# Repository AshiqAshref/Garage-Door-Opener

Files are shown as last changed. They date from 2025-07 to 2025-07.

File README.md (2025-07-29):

# Smart Garage Door Opener

A complete IoT garage door opener system featuring secure Bluetooth Low Energy (BLE) communication, ESP32-C3 microcontroller, custom PCB design, and Android mobile application.

## 🚀 Project Overview

This project implements a modern, secure garage door opener that can be controlled via a smartphone app. The system features:

- **Secure BLE Communication**: Encrypted pairing and authentication
- **ESP32-C3 Based Controller**: Low-power WiFi/BLE microcontroller
- **Custom PCB Design**: Professional circuit board with integrated power management
- **Android Mobile App**: Modern Material Design 3 interface
- **Visual Feedback**: 8-digit LED matrix display for status and pairing codes
- **Physical Controls**: Manual pairing button and factory reset capability

## 📁 Project Structure

```
Garage Door Opener Root/
├── Garage Door Opener Circuit/        # KiCad PCB design files
│   ├── GarageOpener.kicad_sch         # Main schematic
│   ├── GarageOpener.kicad_pcb         # PCB layout
│   ├── production files/              # Gerber files for manufacturing
│   └── parts.txt                      # Bill of materials
├── Garage Door Opener Code/
│   ├── ESP32/                         # Firmware for ESP32-C3
│   │   └── Garage Door Opener/
│   │       ├── src/main.cpp           # Main firmware code
│   │       └── platformio.ini        # PlatformIO configuration
│   └── Android/                       # Android mobile application
│       └── GarageOpenerUI/
│           └── app/src/main/          # Android app source code
├── LICENSE                            # Project license
└── README.md                          # This file
```

## 🔧 Hardware Components

### Main Components
- **ESP32-C3-MINI-1U-N4**: Main microcontroller with WiFi/BLE
- **5V Relay Module**: Controls garage door motor
- **MAX7219 LED Matrix**: 8-digit display for status and pairing codes
- **Buck Converter**: Efficient 5V power supply from mains voltage
- **3.3V Regulator**: Powers ESP32 and logic circuits

### Key Features
- **Input Voltage**: 3.8V - 32V DC input range
- **Power Consumption**: Low-power design with sleep modes
- **Protection**: ESD protection, overcurrent protection
- **Connectivity**: Micro USB for user cusom programming and debugging
- **User Interface**: Physical pairing button, LED status indicators

### PCB Specifications
- **Board Size**: Compact form factor for enclosure mounting
- **Layers**: Multi-layer design for proper power distribution
- **Components**: Surface mount components for reliability
- **Connectors**: Screw terminals for garage door connections

## 💻 Software Features

### ESP32 Firmware
- **Secure BLE Server**: Implements encrypted communication
- **Pairing Management**: Secure device pairing with passkey display
- **Display Controller**: Real-time status updates on LED matrix
- **Memory Management**: Persistent storage of paired devices
- **Factory Reset**: Complete system reset capability

### Android Application
- **Modern UI**: Material Design 3 with Jetpack Compose
- **Device Discovery**: Automatic BLE device scanning
- **Secure Pairing**: Handles BLE security and authentication
- **Device Management**: Save and manage multiple garage door openers
- **Real-time Status**: Live connection status and feedback

## 🔐 Security Features

- **Encrypted BLE Communication**: All data transmitted over encrypted channels
- **Device Authentication**: Secure pairing with passkey verification
- **Bonded Devices**: Only previously paired devices can connect
- **Timeout Protection**: Pairing mode automatically times out
- **Factory Reset**: Complete security reset capability

## 🛠️ Installation & Setup

### Hardware Assembly

1. **PCB Assembly**: Solder all components according to the schematic
2. **Power Connection**: Connect 5-32V DC power supply to input terminals
3. **Relay Wiring**: Connect relay outputs to garage door motor controls
4. **Display Connection**: Wire MAX7219 LED matrix to designated pins
5. **Enclosure**: Mount PCB in weatherproof enclosure

### Firmware Installation

1. **Install PlatformIO**: Set up PlatformIO IDE or VS Code extension
2. **Clone Repository**: Download project files
3. **Configure Platform**: Verify ESP32-C3 platform configuration
4. **Build & Upload**: Compile and flash firmware to ESP32

```bash
cd "Garage Door Opener Code/ESP32/Garage Door Opener"
pio run --target upload
```

### Android App Installation
1. **Easy Install** : Pre built app can be found in ```Garage Door Opener Code/Android/GarageOpenerUI/app/release/app-release.apk``` 

### Android App build
1. **Android Studio**: Open project in Android Studio
2. **Dependencies**: Sync Gradle dependencies
3. **Build Configuration**: Configure signing and build settings
4. **Install**: Build and install APK on Android device

```bash
cd "Garage Door Opener Code/Android/GarageOpenerUI"
./gradlew assembleRelease
```

## 📱 Usage Instructions

### Initial Setup

1. **Power On**: Connect power to the garage door opener
2. **Pairing Mode**: Press and hold the pairing button for 5 seconds
3. **Mobile App**: Open the Android app and scan for devices
4. **Select Device**: Choose "Garage" from the discovered devices list
5. **Enter Passkey**: Input the 6-digit code displayed on the LED matrix
6. **Complete Pairing**: Confirm pairing on both devices

### Daily Operation

1. **Open App**: Launch the Garage Opener app on your phone
2. **Connect**: App automatically connects to paired device
3. **Control**: Tap the garage door button to operate
4. **Status**: Monitor connection status via app interface

### Advanced Features

- **Multiple Devices**: Pair multiple garage door openers
- **Device Management**: Remove or re-pair devices as needed
- **Factory Reset**: Hold pairing button for 10 seconds to reset

## 🔌 Pin Configuration

### ESP32-C3 Pin Assignments
```cpp
#define RELAY_PIN 12        // Garage door relay control
#define BUTTON_PIN 13       // Pairing/reset button
#define DIN_PIN 21          // MAX7219 data input
#define CS_PIN 19           // MAX7219 chip select
#define CLK_PIN 18          // MAX7219 clock
```

### Power Requirements
- **Input Voltage**: 5V - 32V DC
- **ESP32 Current**: ~80mA active, ~10µA deep sleep
- **Relay Current**: ~70mA when activated
- **Display Current**: ~20mA typical

## 🐛 Troubleshooting

### Common Issues

**Cannot pair device:**
- Ensure Bluetooth is enabled on phone
- Verify device is in pairing mode (LED shows passkey)
- Check app permissions for Bluetooth access

**Relay not activating:**
- Verify power supply voltage (5V minimum)
- Check relay connections and wiring
- Test relay manually with multimeter

**Display not working:**
- Confirm MAX7219 connections and power
- Verify pin assignments in firmware
- Check display module with simple test code

**Connection drops frequently:**
- Reduce distance between phone and device
- Check for interference from other 2.4GHz devices
- Verify phone's Bluetooth Low Energy support

## 🔧 Development

### Building from Source

**Requirements:**
- PlatformIO Core 6.0+
- Android Studio Arctic Fox+
- ESP32 Arduino Core 2.0+
- Android API Level 30+

**ESP32 Development:**
```bash
# Install dependencies
pio pkg install

# Build firmware
pio run

# Upload to device
pio run --target upload

# Monitor serial output
pio device monitor
```

**Android Development:**
```bash
# Build debug APK
./gradlew assembleDebug

# Run tests
./gradlew test

# Generate release APK
./gradlew assembleRelease
```

### Code Structure

**ESP32 Firmware:**
- `main.cpp`: Main application logic and BLE server
- `LedController.hpp`: MAX7219 display management
- `platformio.ini`: Build configuration and dependencies

**Android Application:**
- `MainActivity.kt`: Main UI and app lifecycle
- `BleService.kt`: Bluetooth Low Energy communication
- `build.gradle.kts`: Build configuration and dependencies

## 📋 Bill of Materials (BOM)

### Critical Components
| Component | Part Number | Quantity | Description |
|---|---|---|---|
| ESP32-C3-MINI-1U-N4 | ESP32-C3-MINI-1U-N4 | 1 | Main microcontroller |
| Relay | SRD-05VDC-SL-C | 1 | 5V SPDT relay |
| Buck Converter IC | TBD | 1 | 5V switching regulator |
| LED Matrix | MAX7219 8-digit | 1 | Status display |
| Capacitors | Various | Multiple | Power filtering |
| Resistors | Various | Multiple | Pull-ups and current limiting |

*See `parts.txt` for complete component specifications*

## 🤝 Contributing

Contributions are welcome! Please follow these guidelines:

1. **Fork the Repository**: Create your own fork
2. **Create Feature Branch**: `git checkout -b feature/new-feature`
3. **Commit Changes**: Use descriptive commit messages
4. **Push Branch**: `git push origin feature/new-feature`
5. **Create Pull Request**: Submit PR with detailed description

### Development Standards
- Follow existing code style and formatting
- Add comments for complex logic
- Test thoroughly before submitting
- Update documentation as needed

## 📄 License

This project is licensed under the MIT License - see the [LICENSE](LICENSE) file for details.

## ⚠️ Safety Warning

**ELECTRICAL SAFETY**: This device interfaces with garage door motors that operate at dangerous voltages. Installation should only be performed by qualified electricians. Always disconnect power before making connections.

**SECURITY**: While this system implements encryption, no system is 100% secure. Use appropriate physical security measures for your garage.

## 📞 Support

For questions, issues, or contributions:
- **Issues**: Use GitHub Issues for bug reports
- **Discussions**: GitHub Discussions for general questions
- **Email**: Contact project maintainer for urgent issues

## 🔄 Version History

- **v1.0**: Initial release with basic BLE functionality
- **Future**: Planned features include WiFi connectivity, web interface, and voice control integration

---

**Built with ❤️ for the maker community**

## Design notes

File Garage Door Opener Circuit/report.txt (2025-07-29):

Plotted to 'E:\Project\Kicad\firstTry\firstTry.pdf'.

Info: Done.
Plotted to 'E:\Project\Kicad\firstTry\firstTry.pdf'.

Info: Done.
Info: Done.
Info: Done.

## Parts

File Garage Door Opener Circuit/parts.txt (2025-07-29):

tantalum cap C6- TAJA226K010TNJ or TAJA226K010RNJ esr betwen 0.2 Ohm to 10 Ohm
C1 - CAPACITOR_SMD CER 1uf 603 : CL10B105KO8NNNC, CL10B105KO8NNNC
C4 - CL31B106KAHNNNE 10uf +/-10% 25V 1206

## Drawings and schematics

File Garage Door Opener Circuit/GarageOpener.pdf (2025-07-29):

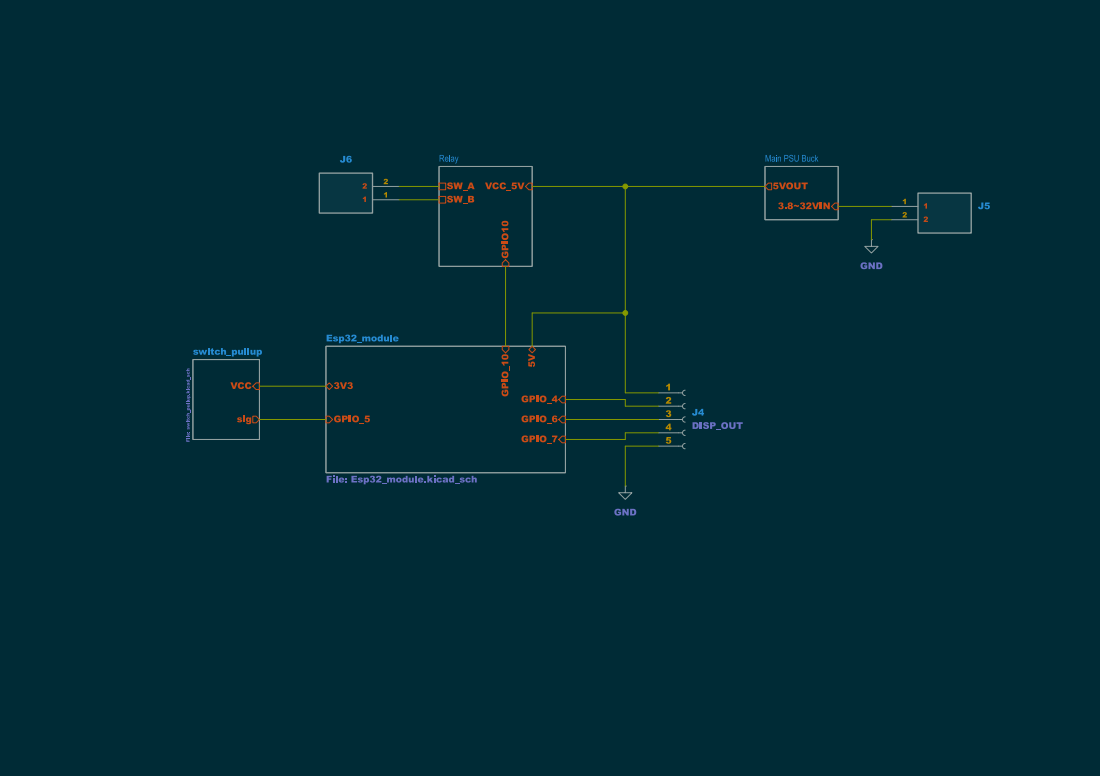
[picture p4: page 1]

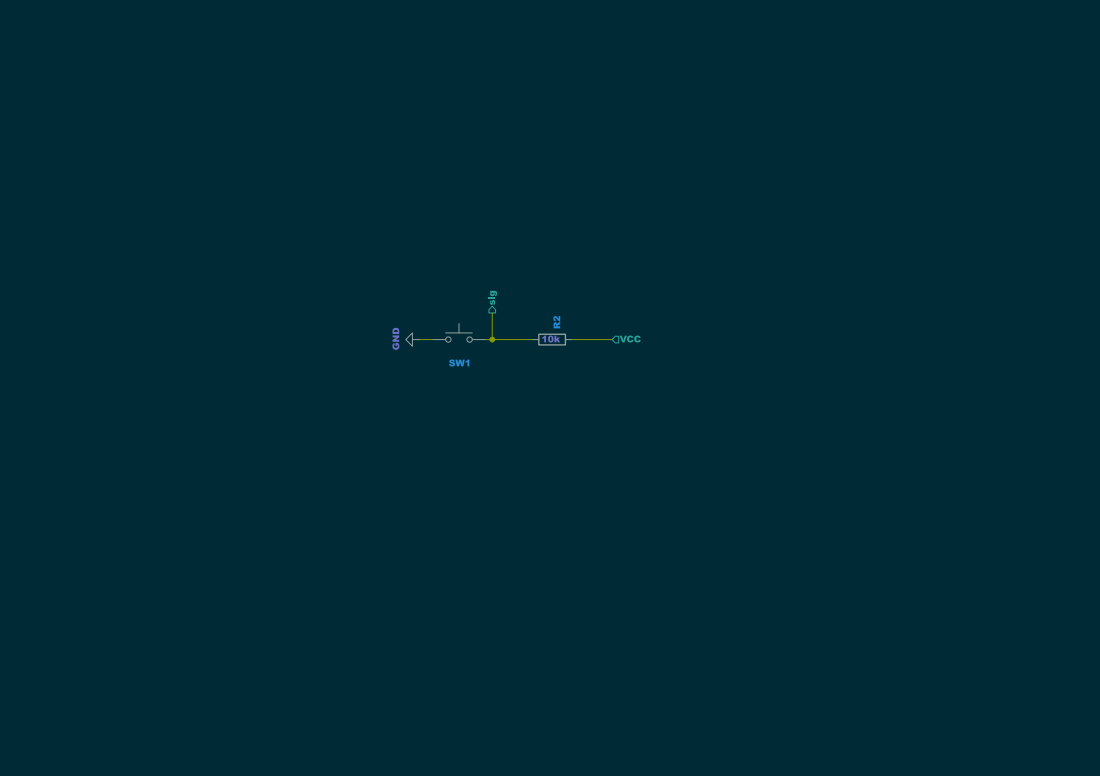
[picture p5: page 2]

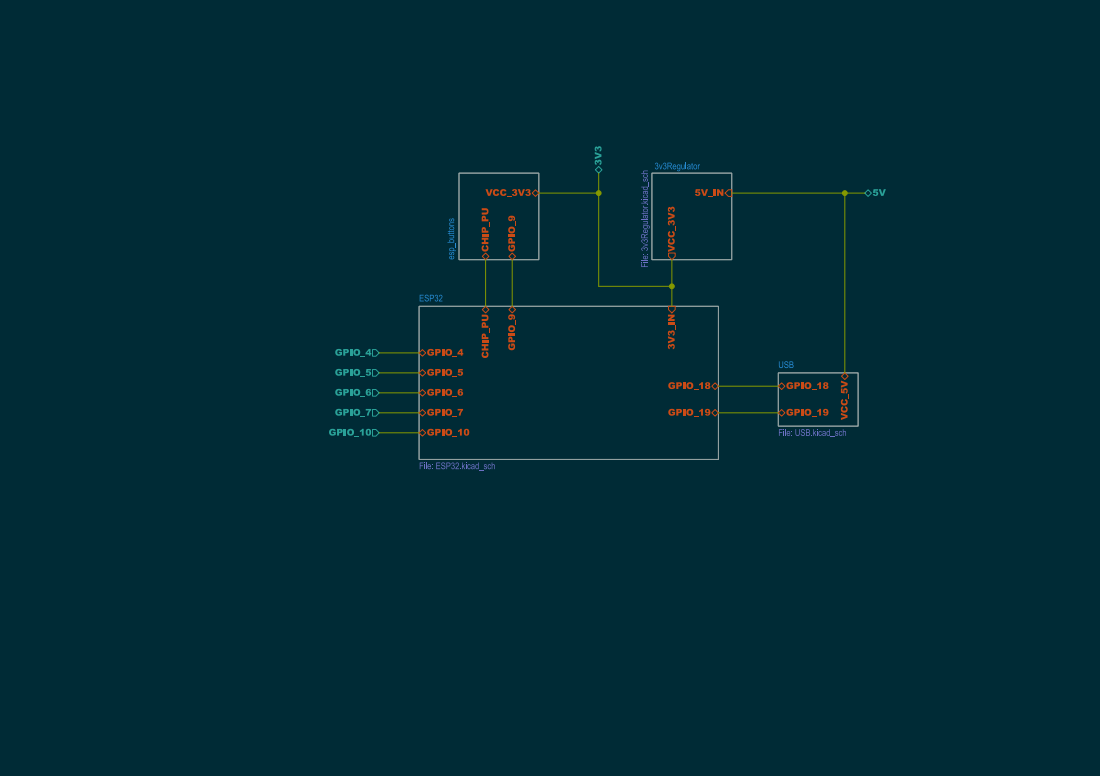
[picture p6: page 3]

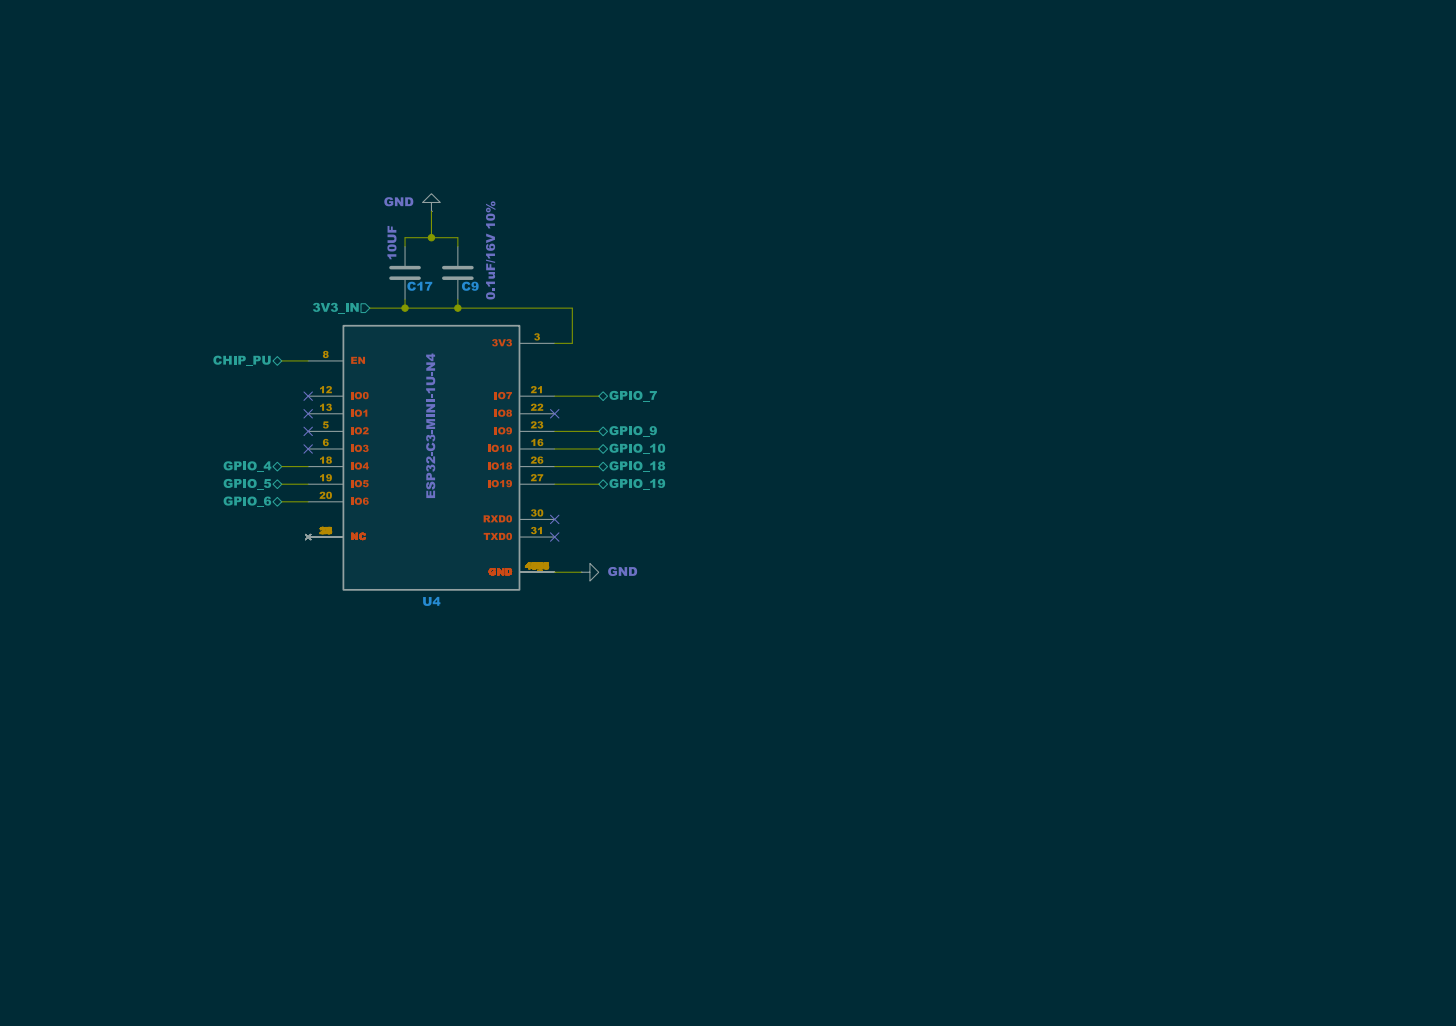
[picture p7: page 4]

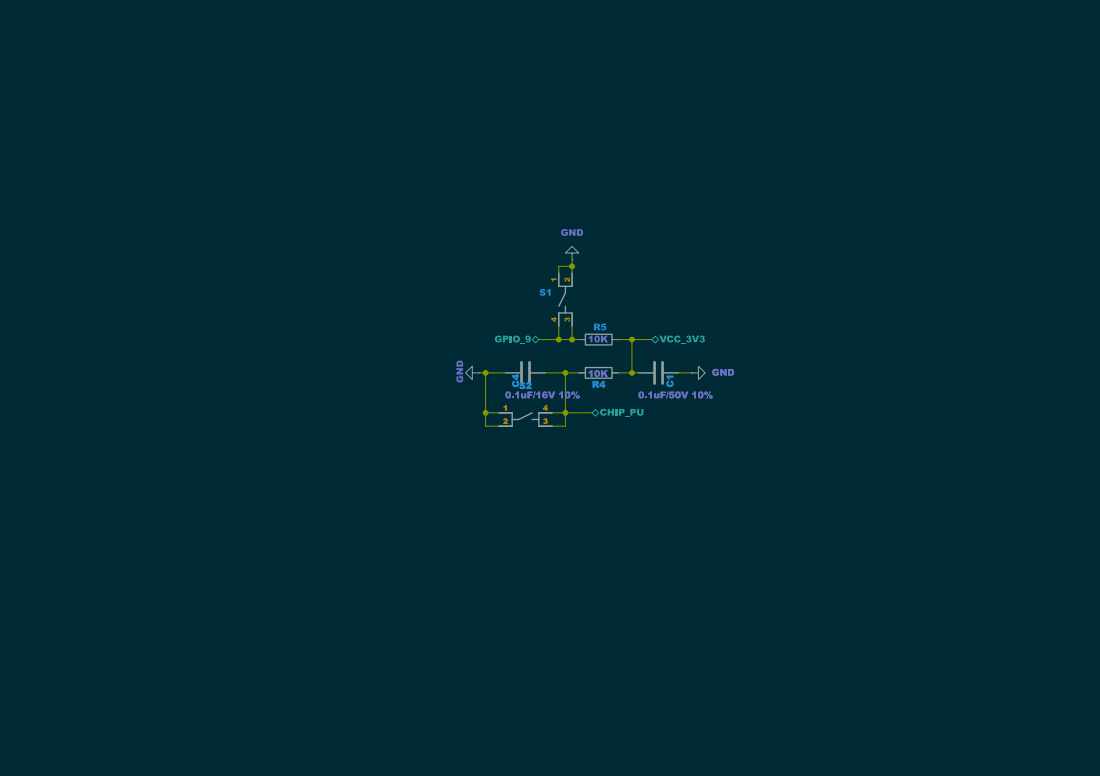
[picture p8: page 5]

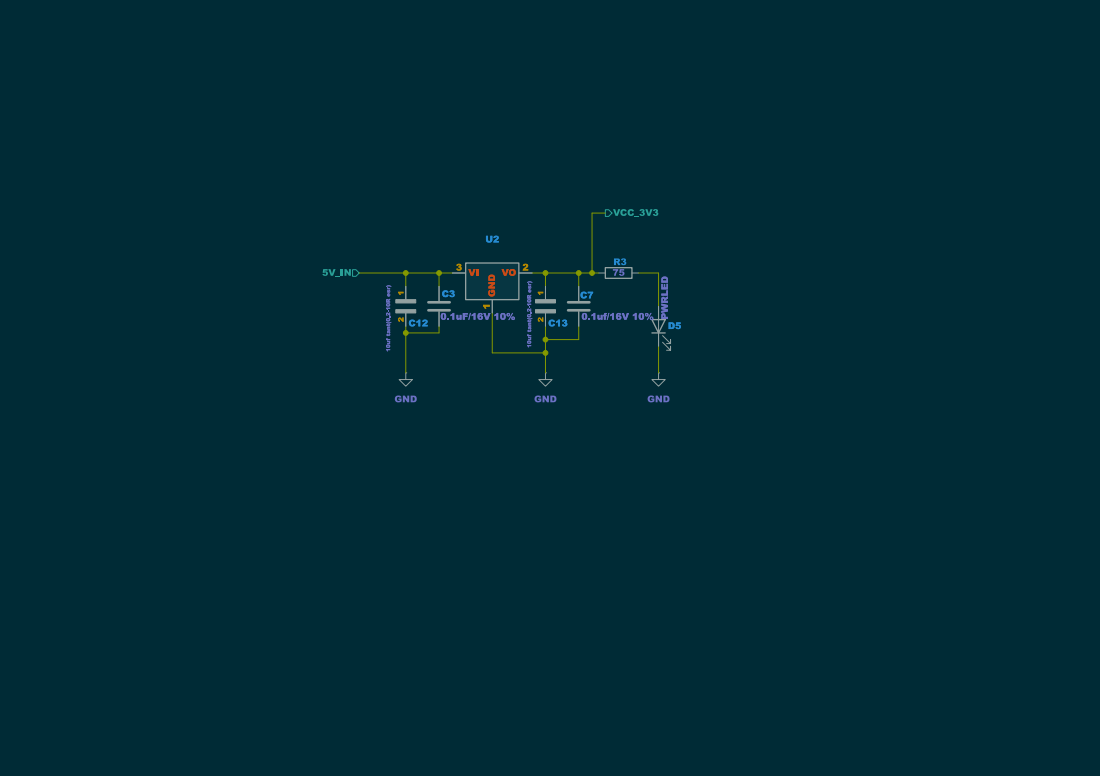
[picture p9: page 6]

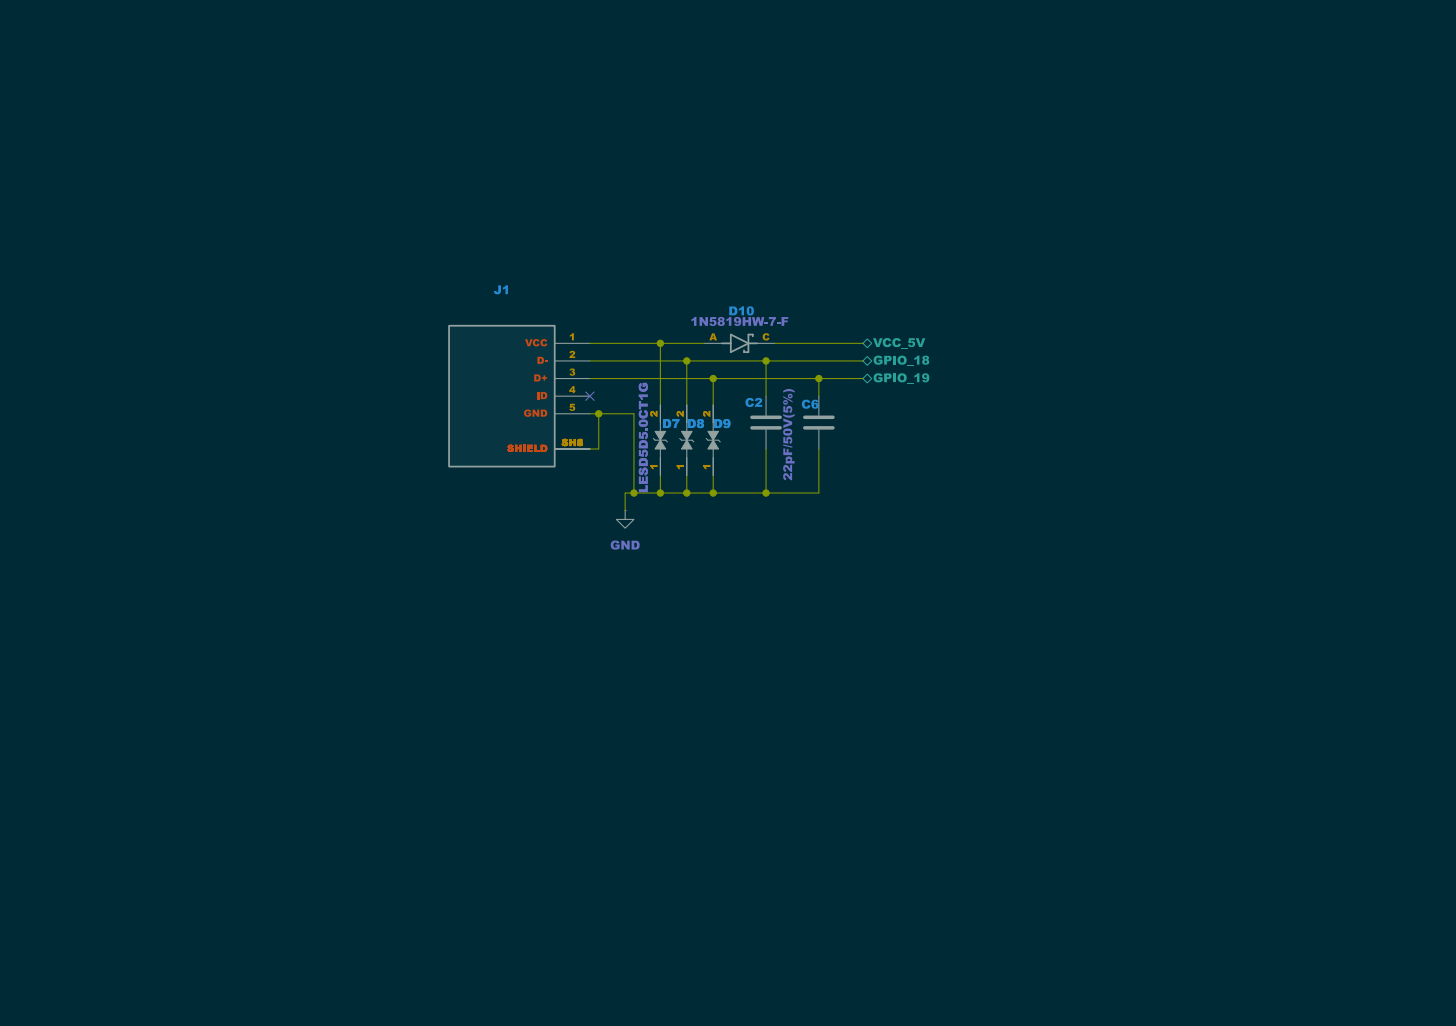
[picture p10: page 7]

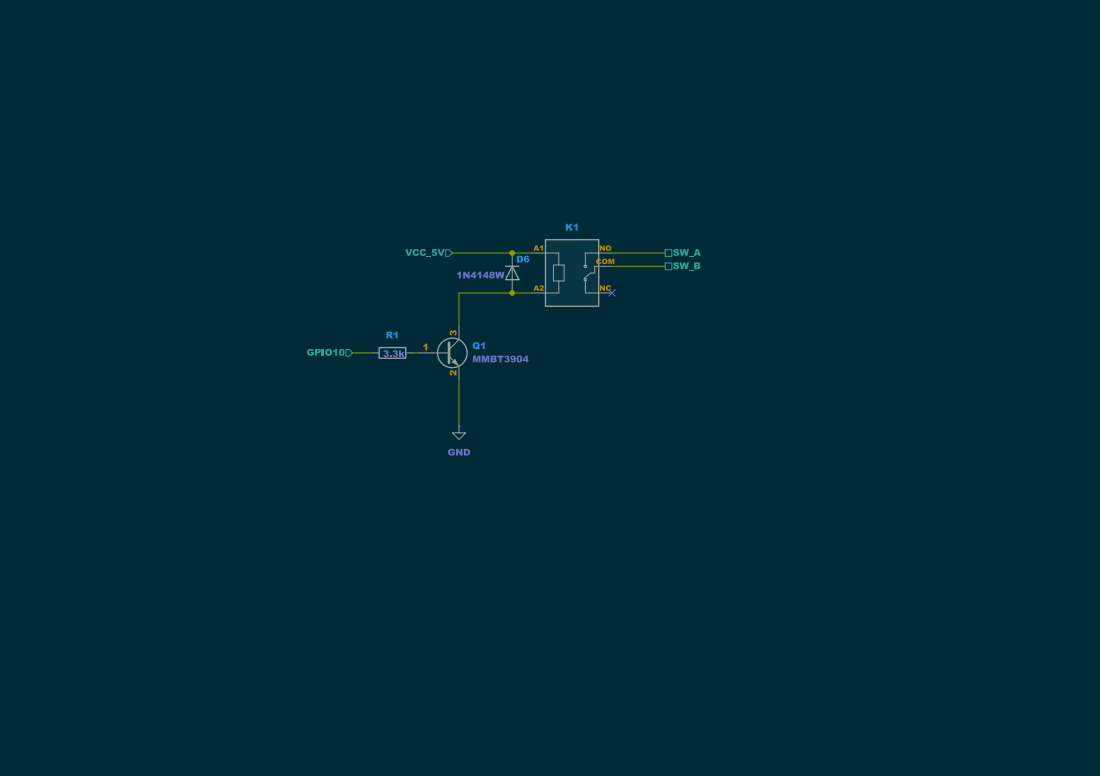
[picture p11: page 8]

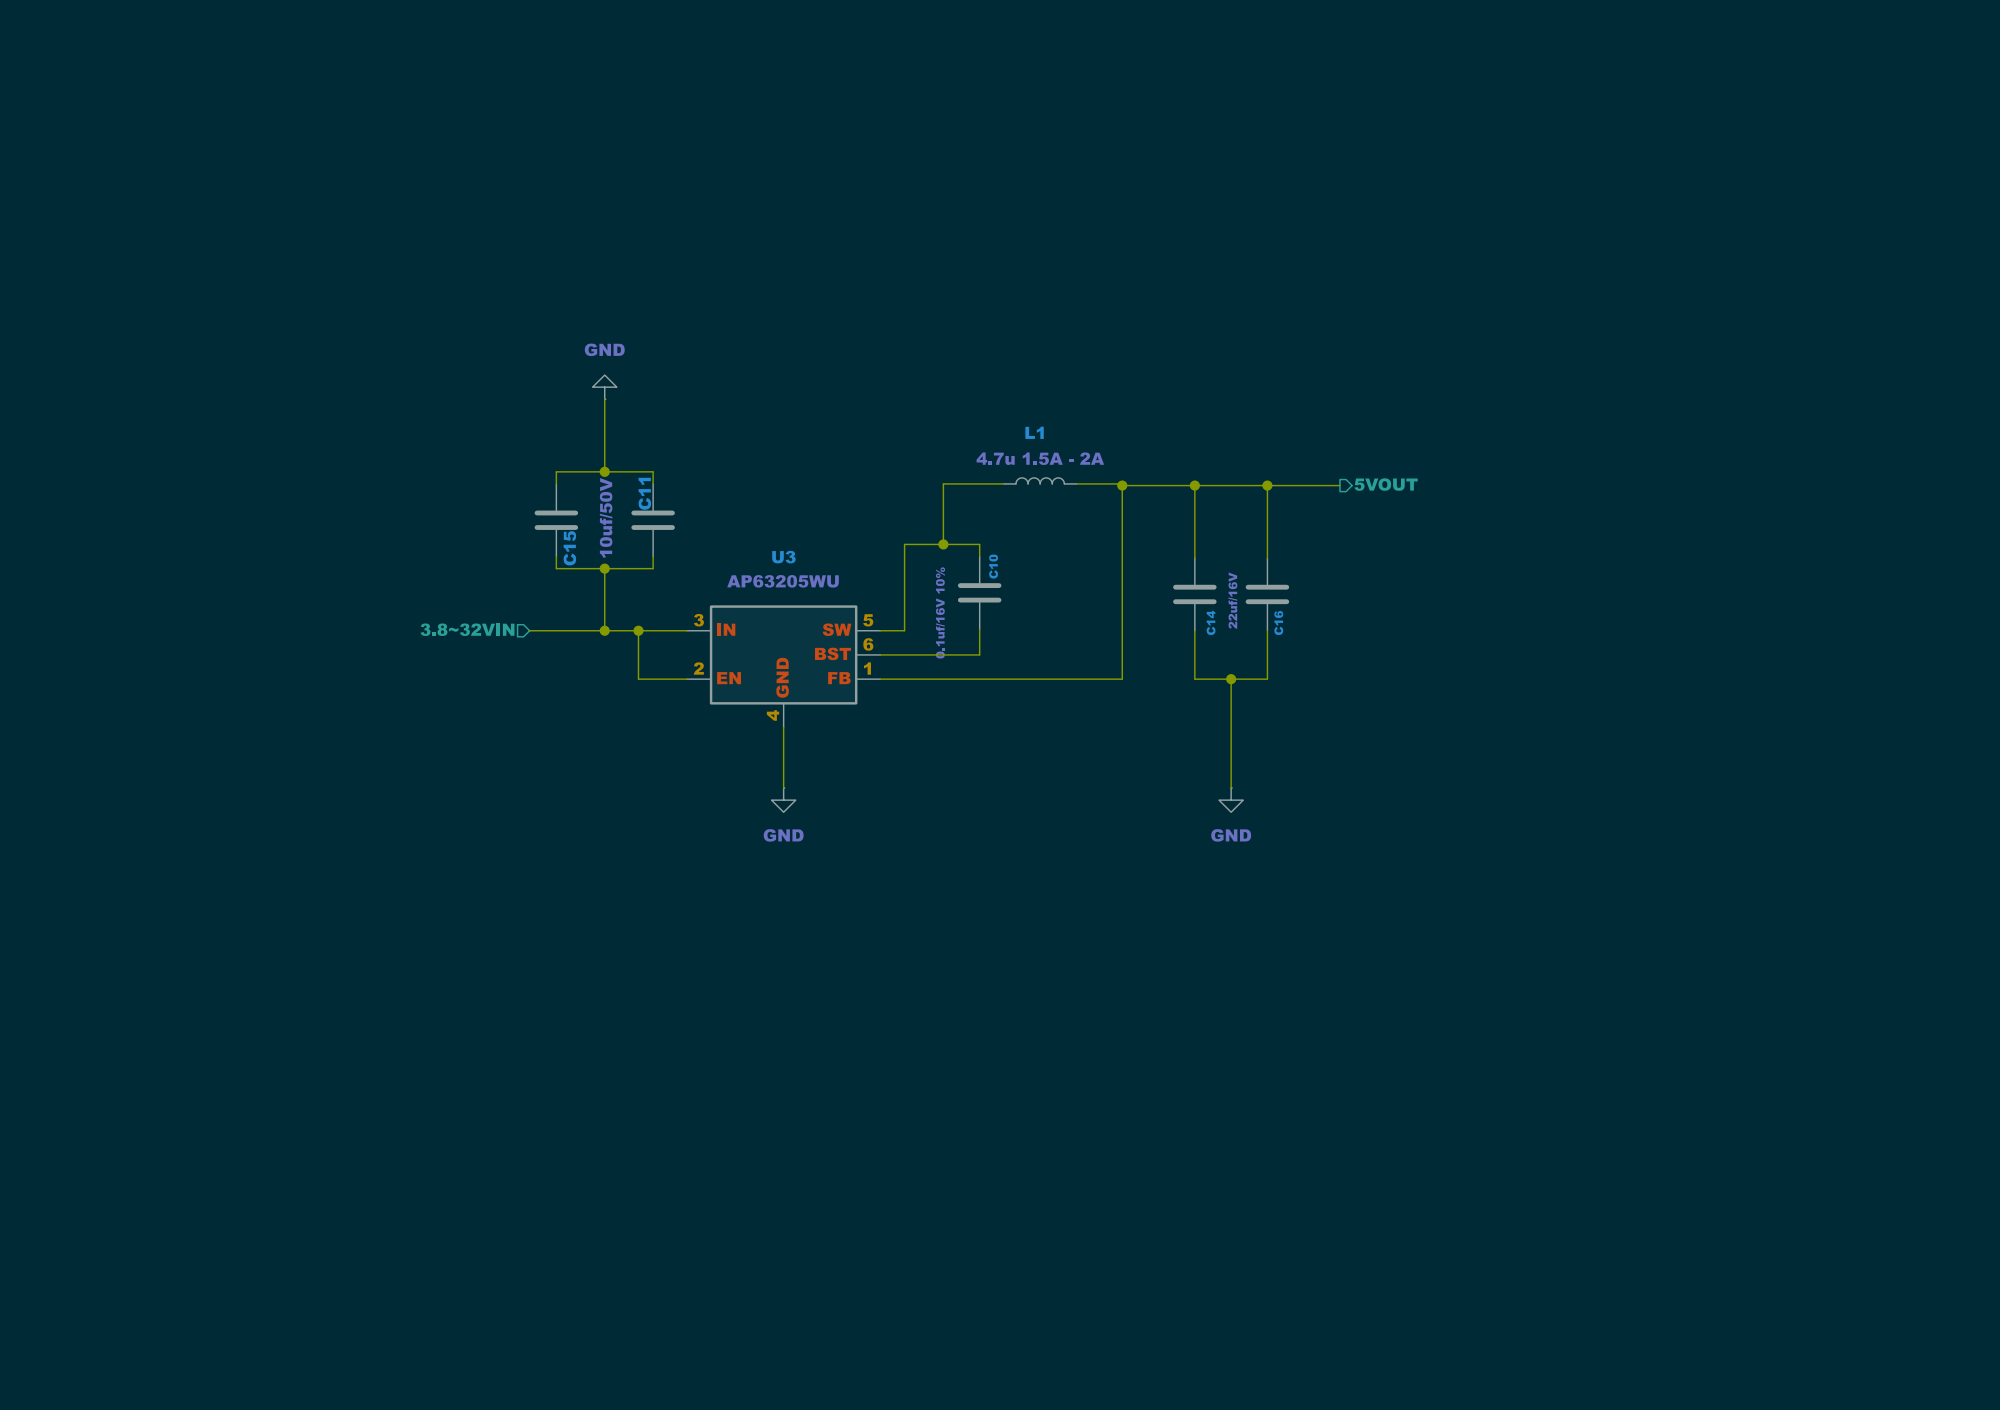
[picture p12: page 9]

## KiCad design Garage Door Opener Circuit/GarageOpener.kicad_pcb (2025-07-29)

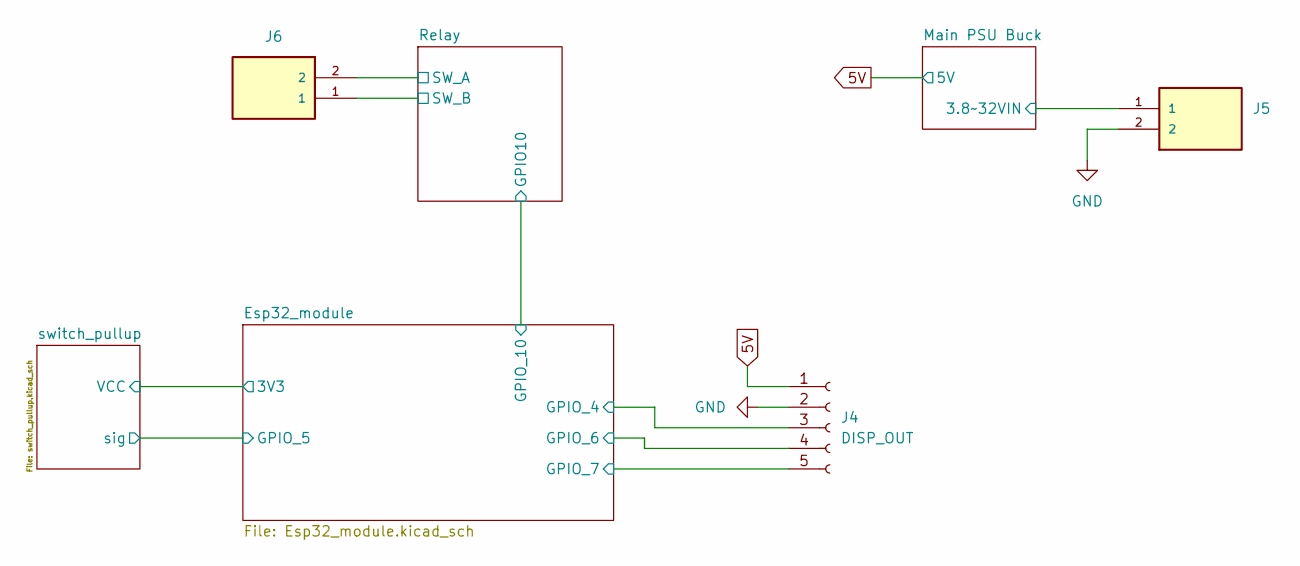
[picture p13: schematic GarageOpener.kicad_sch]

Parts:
J4: DISP_OUT; PinHeader_1x05_P2.54mm_Vertical
J5, J6: TB002-500-02BE; CUI_TB002-500-02BE

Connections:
5V: J4.1; also elsewhere on the board
/Esp32_module/GPIO_4: J4.3; also elsewhere on the board
/Esp32_module/GPIO_6: J4.4; also elsewhere on the board
/Esp32_module/GPIO_7: J4.5; also elsewhere on the board
/Main PSU Buck/3.8~32VIN: J5.1; also elsewhere on the board
/Relay/SW_A: J6.2; also elsewhere on the board
/Relay/SW_B: J6.1; also elsewhere on the board
GND: J4.2, J5.2; also elsewhere on the board

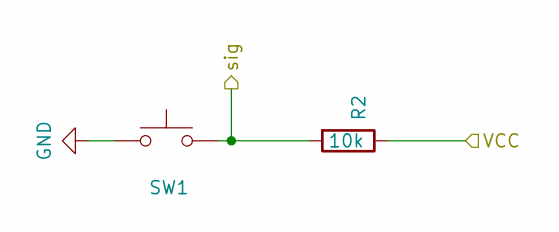
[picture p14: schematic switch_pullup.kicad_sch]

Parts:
R2: 10k; R_0402_1005Metric
SW1: SW_Push; SW_SPST_PTS645Sx43SMTR92

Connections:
3V3: R2.1; also elsewhere on the board
/Esp32_module/GPIO_5: R2.2, SW1.2; also elsewhere on the board
GND: SW1.1; also elsewhere on the board

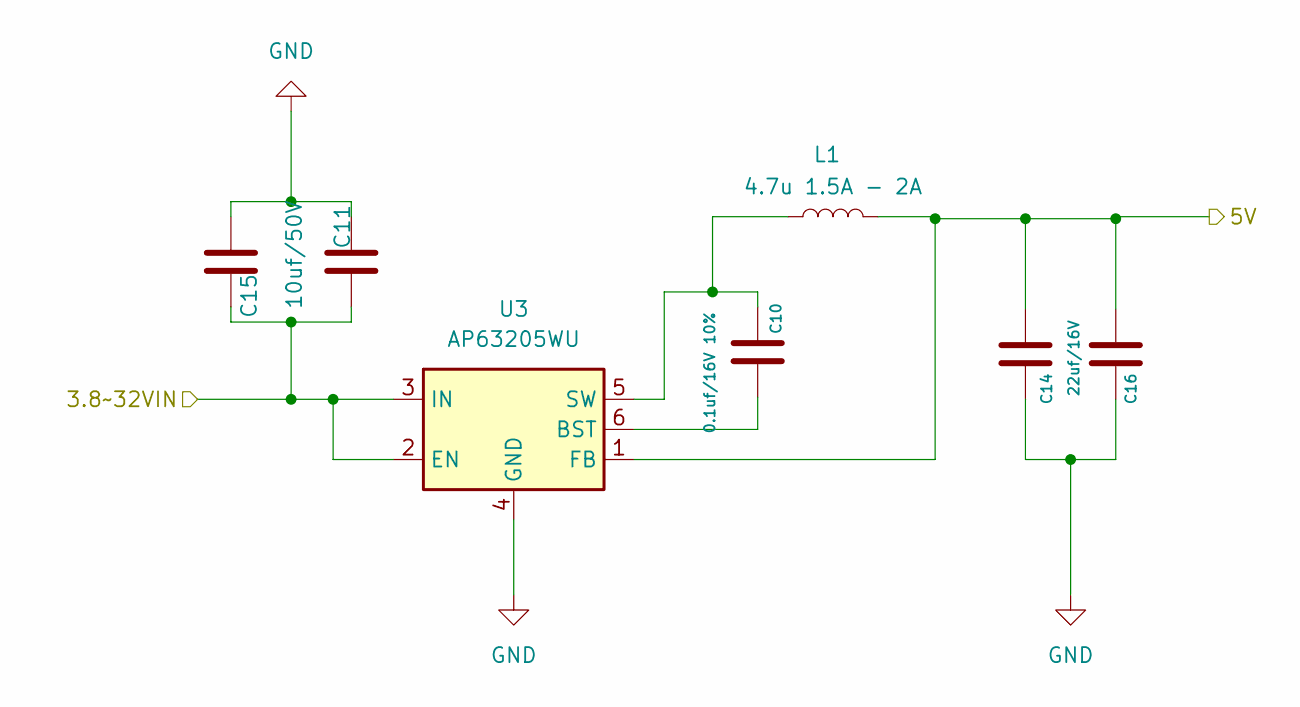
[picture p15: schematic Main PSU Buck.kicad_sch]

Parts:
C10: 0.1uf/16V 10%; C_0201_0603Metric
C11, C15: 10uf/50V; CAPC3225X270N
C14, C16: 22uf/16V; CAPC1608X100N
L1: 4.7u 1.5A - 2A; IND_NRS5030T100MMGJ_TAY
U3: AP63205WU; TSOT-23-6

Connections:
5V: C14.1, C16.1, L1.2, U3.1 (FB); also elsewhere on the board
/Main PSU Buck/3.8~32VIN: C11.2, C15.2, U3.2 (EN), U3.3 (IN); also elsewhere on the board
GND: C11.1, C14.2, C15.1, C16.2, U3.4 (GND); also elsewhere on the board
unnamed: C10.2, U3.6 (BST)
unnamed: C10.1, L1.1, U3.5 (SW)

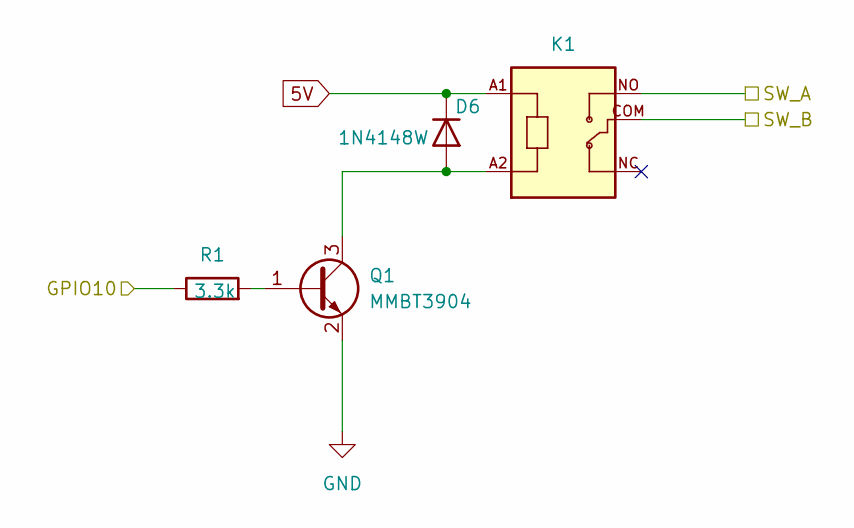
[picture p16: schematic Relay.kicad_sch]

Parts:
D6: 1N4148W; D_SOD-123
K1: SRD-05VDC-SL-C; RELAY_SRD-05VDC-SL-C
Q1: MMBT3904; SOT-23
R1: 3.3k; R_0603_1608Metric

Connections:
5V: D6.1 (K), K1.A1; also elsewhere on the board
/Esp32_module/GPIO_10: R1.1; also elsewhere on the board
/Relay/SW_A: K1.NO; also elsewhere on the board
/Relay/SW_B: K1.COM; also elsewhere on the board
GND: Q1.2 (E); also elsewhere on the board
unnamed: D6.2 (A), K1.A2, Q1.3 (C)
unnamed: Q1.1 (B), R1.2

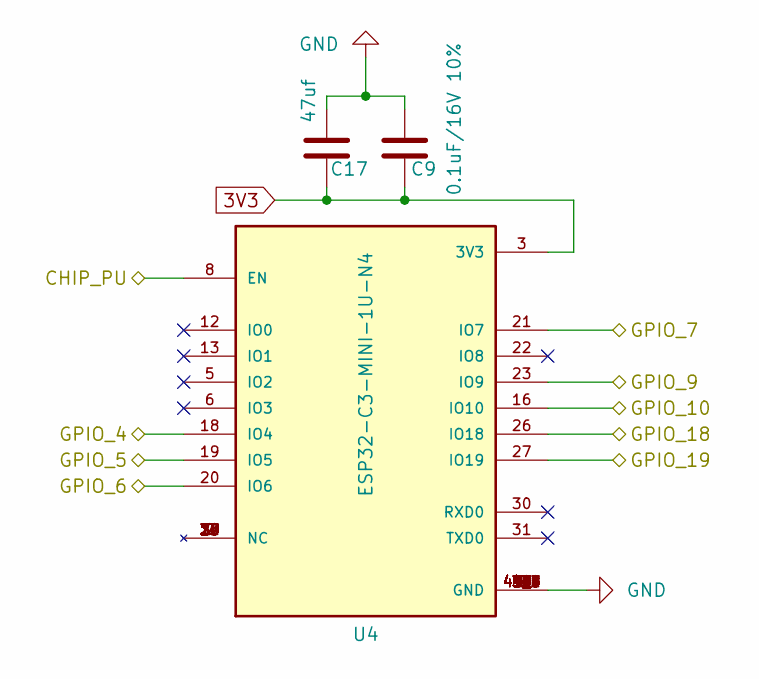
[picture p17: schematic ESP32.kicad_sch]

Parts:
C9: 0.1uF/16V 10%; VARC3216X85N
C17: 47uf; C_1206_3216Metric
U4: ESP32-C3-MINI-1U-N4; XCVR_ESP32-C3-MINI-1U-N4; PARTREV v1.0

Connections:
3V3: C9.1, C17.1, U4.3 (3V3); also elsewhere on the board
/Esp32_module/ESP32/CHIP_PU: U4.8 (EN); also elsewhere on the board
/Esp32_module/ESP32/GPIO_9: U4.23 (IO9); also elsewhere on the board
/Esp32_module/ESP32/GPIO_18: U4.26 (IO18); also elsewhere on the board
/Esp32_module/ESP32/GPIO_19: U4.27 (IO19); also elsewhere on the board
/Esp32_module/GPIO_4: U4.18 (IO4); also elsewhere on the board
/Esp32_module/GPIO_5: U4.19 (IO5); also elsewhere on the board
/Esp32_module/GPIO_6: U4.20 (IO6); also elsewhere on the board
/Esp32_module/GPIO_7: U4.21 (IO7); also elsewhere on the board
/Esp32_module/GPIO_10: U4.16 (IO10); also elsewhere on the board
GND: C9.2, C17.2, U4.1 (GND), U4.2 (GND), U4.11 (GND), U4.14 (GND), U4.36 (GND), U4.37 (GND), U4.38 (GND), U4.39 (GND), U4.40 (GND), U4.41 (GND), U4.42 (GND), U4.43 (GND), U4.44 (GND), U4.45 (GND), U4.46 (GND), U4.47 (GND), U4.48 (GND), U4.49_1 (GND), U4.49_2 (GND), U4.49_3 (GND), U4.49_4 (GND), U4.49_5 (GND), U4.49_6 (GND), U4.49_7 (GND), U4.49_8 (GND), U4.49_9 (GND), U4.50 (GND), U4.51 (GND), U4.52 (GND), U4.53 (GND); also elsewhere on the board

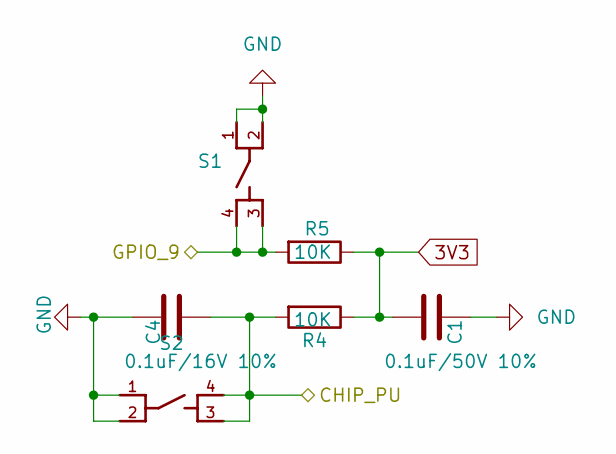
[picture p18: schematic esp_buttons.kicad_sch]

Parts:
C1: 0.1uF/50V 10%; C_0201_0603Metric
C4: 0.1uF/16V 10%; C_0201_0603Metric
R4, R5: 10K; R_0402_1005Metric
S1, S2: PTS526_SMG15_SMTR2_LFS; SW_PTS526_SMG15_SMTR2_LFS

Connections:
3V3: C1.1, R4.1, R5.1; also elsewhere on the board
/Esp32_module/ESP32/CHIP_PU: C4.2, R4.2, S2.3, S2.4; also elsewhere on the board
/Esp32_module/ESP32/GPIO_9: R5.2, S1.3, S1.4; also elsewhere on the board
GND: C1.2, C4.1, S1.1, S1.2, S2.1, S2.2; also elsewhere on the board

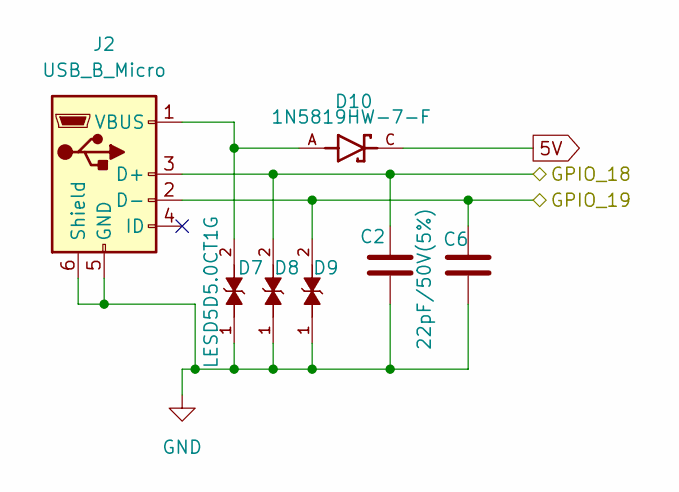
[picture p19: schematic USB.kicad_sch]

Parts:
C2, C6: 22pF/50V(5%); C_0201_0603Metric
D7, D8, D9: LESD5D5.0CT1G; TVS_LESD5D5.0CT1G; PARTREV O
D10: 1N5819HW-7-F; SOD3715X145N; PARTREV 18-2; DigiKey_Part_Number 1N5819HW-FDITR-ND
J2: USB_B_Micro; USB_Micro-B_Amphenol_10118194_Horizontal

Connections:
5V: D10.C; also elsewhere on the board
/Esp32_module/ESP32/GPIO_18: C2.1, D8.2, J2.3 (D+); also elsewhere on the board
/Esp32_module/ESP32/GPIO_19: C6.1, D9.2, J2.2 (D-); also elsewhere on the board
GND: C2.2, C6.2, D7.1, D8.1, D9.1, J2.5 (GND), J2.6 (Shield); also elsewhere on the board
unnamed: D7.2, D10.A, J2.1 (VBUS)

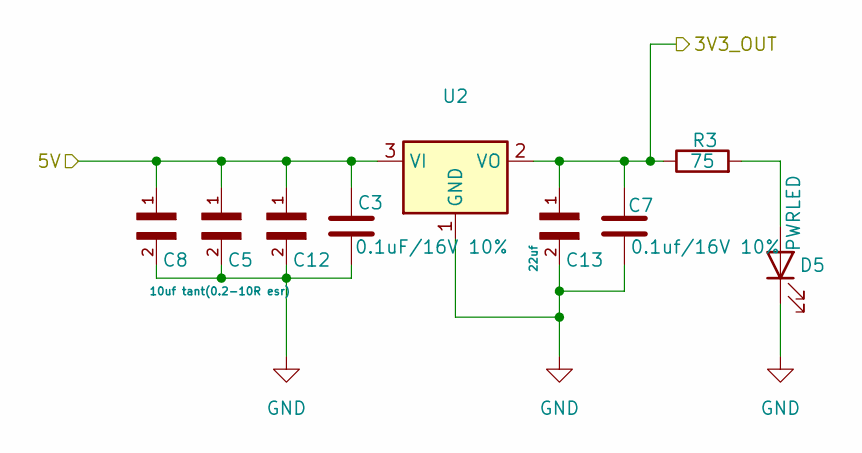
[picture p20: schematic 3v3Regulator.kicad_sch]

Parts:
C3: 0.1uF/16V 10%; VARC3216X85N
C5, C8, C12: 10uf tant(0.2-10R esr); C_1206_3216Metric
C7: 0.1uf/16V 10%; VARC3216X85N
C13: 22uf; C_1206_3216Metric
D5: PWRLED; 0603
R3: 75; R_0402_1005Metric
U2: AMS1117-3.3; SOT-223-3_TabPin2

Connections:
3V3: C7.1, C13.1, R3.1, U2.2 (VO); also elsewhere on the board
5V: C3.1, C5.1, C8.1, C12.1, U2.3 (VI); also elsewhere on the board
GND: C3.2, C5.2, C7.2, C8.2, C12.2, C13.2, D5.1 (K), U2.1 (GND); also elsewhere on the board
unnamed: D5.2 (A), R3.2

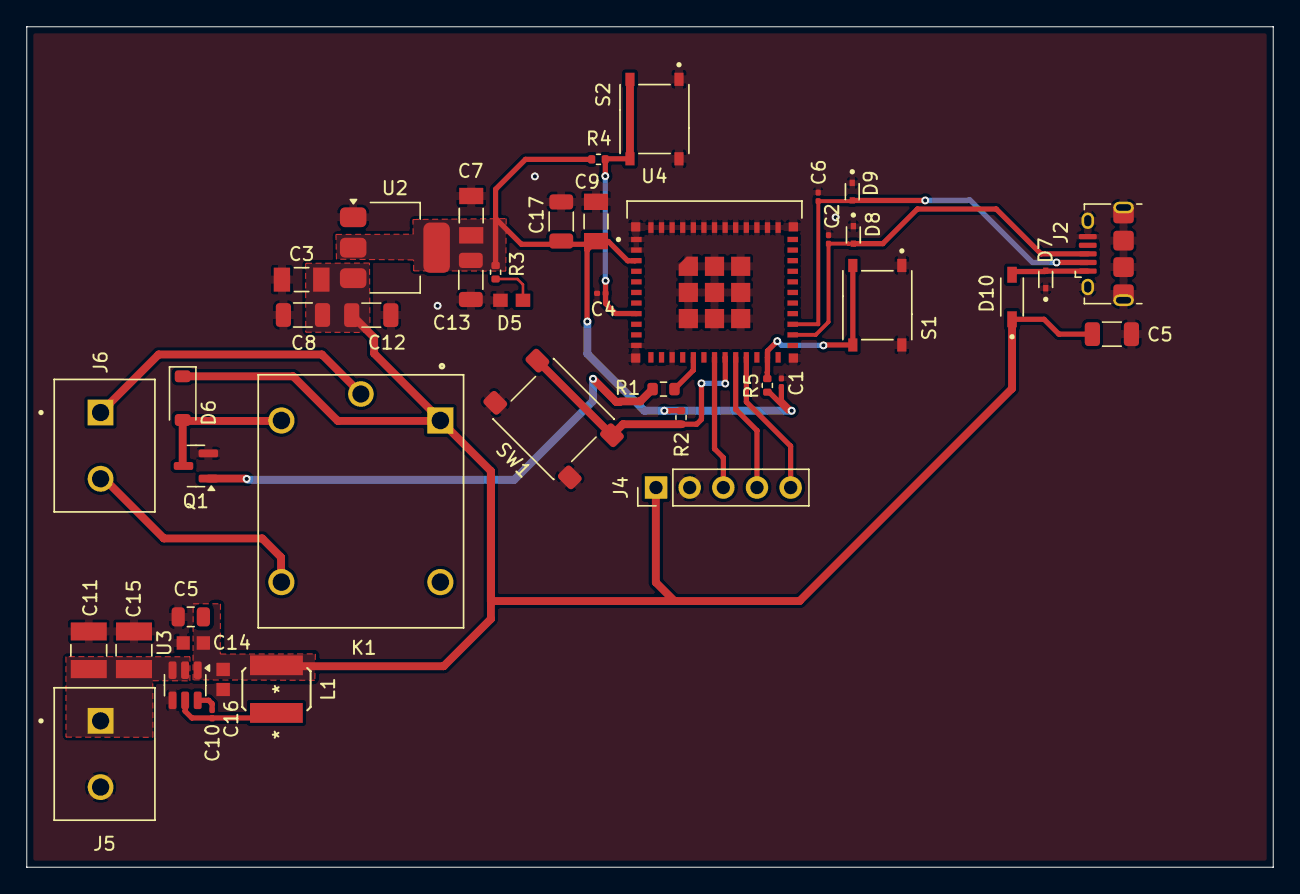
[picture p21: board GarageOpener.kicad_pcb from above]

Board: 2 copper layers, 94.1 x 63.5 mm, 42 parts (0 on the bottom side), 21 nets.

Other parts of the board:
C5#2: 0.1uF/16V 10%; C_0805_2012Metric

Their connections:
GND: C5#2.2; also elsewhere on the board

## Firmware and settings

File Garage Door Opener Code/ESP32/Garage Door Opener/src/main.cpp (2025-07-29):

#include <Arduino.h>
#include <BLEDevice.h>
#include <BLEUtils.h>
#include <BLEServer.h>
#include <BLE2902.h>

#include "LedController.hpp"
#include <Preferences.h>

#include "esp_gap_ble_api.h" // Required for esp_ble_get_bond_device_num() and esp_ble_get_bond_device_list()
#include "esp_bt.h"         // Required for esp_ble_bond_dev_t struct definition

// GPIO pin connected to the relay that controls the garage door
#define RELAY_PIN 12
// #define BUTTON_PIN 27
#define BUTTON_PIN 13

// GPIO pins for the MAX7219 LED Matrix 8 digit display
constexpr int DIN_PIN = 21;
constexpr int CS_PIN  = 19;
constexpr int CLK_PIN = 18;

// UUID generator : https://www.uuidgenerator.net/
#define SERVICE_UUID        "9ba08ea3-3fa9-4622-bae5-bdd3f0c7fedf" // Example Service UUID
#define CHARACTERISTIC_UUID "427c5c12-0f90-46be-ba43-7e4a207be489" // Example Characteristic UUID

// Global pointers for BLE objects
BLEServer* pServer = nullptr;
BLECharacteristic* pCharacteristic = nullptr;

// Create an instance of the LedController
LedController lc = LedController();

// Flags to track connection status for re-advertising
bool deviceConnected = false;
bool oldDeviceConnected = false;

uint32_t currentDisplayedPasskey = 0;

//pairing button
constexpr unsigned long PAIRING_PRESS_DURATION_MILLIS = 5000; // 5 seconds
constexpr unsigned long PAIRING_WINDOW_TIMEOUT_MILLIS = 60000; // Advertising active for 60 seconds if no connection
constexpr unsigned long FACTORY_RESET_PRESS_DURATION = 5000; // 5 seconds for factory reset
bool pairingModeActive = false;  // True if the device is currently advertising for new pairings
bool allowNewPairing = false;    // Only true during explicit pairing mode activated by button
unsigned long buttonPressStartTime = 0; // Tracks when the pairing button was first pressed
unsigned long pairingModeStartTime = 0; // Tracks when pairing mode was activated, for timeout

unsigned long lastDisplayUpdate = 0; // Timestamp for the last display update


Preferences preferences;

// Add this function to your code
void clearBondedDevices() {
    Serial.println("Clearing all bonded devices from NVS...");
    preferences.begin("nvs", false); // Open preferences with namespace "nvs" where ESP32 BT/BLE info is stored
    preferences.clear(); // Clear all preferences under this namespace
    preferences.end(); // Close the preferences

    Serial.println("All bonded devices have been removed. Restarting...");
    ESP.restart();
}

// Function to list all currently bonded devices stored in NVS flash
void listBondedDevices() {
    Serial.println("\n--- Listing Bonded Devices ---");

    // Get the number of bonded devices
    int dev_num = esp_ble_get_bond_device_num(); 

    if (dev_num <= 0) {
        Serial.println("No bonded devices found.");
        return;
    }

    // Allocate memory to hold the list of bonded device structures
    // It's crucial to free this memory after use.
    auto *bond_dev_list = static_cast<esp_ble_bond_dev_t *>(heap_caps_malloc(sizeof(esp_ble_bond_dev_t) * dev_num,
                                                                             MALLOC_CAP_INTERNAL | MALLOC_CAP_8BIT));

    if (!bond_dev_list) {
        Serial.println("ERROR: Failed to allocate memory for bond device list.");
        return;
    }

    // Retrieve the list of bonded devices
    // The first argument `&dev_num` will be updated with the actual number of devices retrieved.
    esp_ble_get_bond_device_list(&dev_num, bond_dev_list);

    Serial.printf("%d bonded device(s) found:\n", dev_num);
    for (int i = 0; i < dev_num; i++) {
        // Print the MAC address of each bonded device
        Serial.printf("  Device %d: %02X:%02X:%02X:%02X:%02X:%02X\n", i + 1,
                        bond_dev_list[i].bd_addr[0], bond_dev_list[i].bd_addr[1],
                        bond_dev_list[i].bd_addr[2], bond_dev_list[i].bd_addr[3],
                        bond_dev_list[i].bd_addr[4], bond_dev_list[i].bd_addr[5]);
        // You could also inspect bond_dev_list[i].addr_type if you need to differentiate
        // between public and random addresses, though for most uses, the address itself is enough.
    }

    // Free the allocated memory to prevent memory leaks
    heap_caps_free(bond_dev_list); 
    Serial.println("--- End of Bonded Devices List ---");
}


void displayString(const String& str, uint8_t startSegment, const String& prefix = "") {
    if (pairingModeActive && currentDisplayedPasskey > 0) {
        return; // If pairing mode is active, do not update the display with passkeys
    }
    lastDisplayUpdate = millis(); // Update the timestamp for the last display update
    lc.clearMatrix();  
    const uint32_t len = str.length();
    
    uint8_t segPos;
    if(startSegment > 7) { len>7 ? segPos = 7: segPos=len; } 
    else { segPos = 7 - startSegment; }
    
    if(prefix.length() > 0) {
        byte charAtPos = 0;
        for (int i = 7; i > segPos; i--) {
            i-1 <= segPos ?
            lc.setChar(0, i, prefix.charAt(charAtPos++), true):
            lc.setChar(0, i, prefix.charAt(charAtPos++), false);
        }
    }
    
    for (int i = 0; i < len; i++) {
        char charToDisplay = str.charAt(i);
        lc.setChar(0, segPos--, charToDisplay, false);
        if (segPos==0 && i+2 < len) {
            lc.setChar(0, segPos, '-', false);
            break; 
        }
    }
}

void displayString(uint32_t numberInt, uint8_t startSegment, const String& prefix = "") {
    String numberStr = String(numberInt);
    displayString(numberStr, startSegment, prefix);
}

void displayClear(){
    if (currentDisplayedPasskey == 0){
        lc.clearMatrix();
        lastDisplayUpdate = 0;
    }
    
}

void knightRiderEffect(){
    for (int i = 0; i < 8; i++) {
        lc.setColumn(0, i, 0b11111111);
        delay(40);
        lc.setColumn(0, i, 0b00000000);
    }
    for (int i = 6; i > 0; i--) {
        lc.setColumn(0, i, 0b11111111);
        delay(40);
        lc.setColumn(0, i, 0b00000000);
    }
    lc.clearMatrix();
}

void displayPattern(uint32_t duration){
    lc.clearMatrix();
    uint32_t startMillis = millis();
    while (millis() - startMillis < duration) {
        knightRiderEffect();
        delay(200);
    }
}


/**
 * Monitors a button press for a specified duration.
 * Displays a countdown timer while button is pressed.
 * 
 * @param buttonPin The GPIO pin connected to the button
 * @param requiredDuration The required press duration in milliseconds
 * @param prefixText Optional text prefix for the display (default: "")
 * @return true if button was held for the entire duration, false otherwise
 */
bool waitForButtonPressDuration(const uint8_t buttonPin, const unsigned long requiredDuration, const String& prefixText = "") {
    const unsigned long startTime = millis();
    unsigned long secondsRemaining = requiredDuration / 1000;
    unsigned long lastDisplayedSecond = secondsRemaining;
    delay(15);
    if (digitalRead(buttonPin) == HIGH){
        while (digitalRead(buttonPin) == HIGH) {
            const unsigned long elapsedTime = millis() - startTime;
            
            secondsRemaining = ((requiredDuration - elapsedTime) / 1000);
            if (secondsRemaining != lastDisplayedSecond) {
                lastDisplayedSecond = secondsRemaining;
                displayString(secondsRemaining, prefixText.length(), prefixText);
                Serial.println("Hold for " + String(secondsRemaining) + " more seconds...");
            }
            
            if (elapsedTime >= requiredDuration) {displayClear(); return true; }
            delay(10);
        }
        displayClear();
    }
    
    return false; 
}


// --- 1. BLE Server Callbacks (for connection/disconnection events) ---
class MyServerCallbacks: public BLEServerCallbacks {
    void onConnect(BLEServer* pServer, esp_ble_gatts_cb_param_t *param) override {
        Serial.println("Device connected. Starting secure connection process...");

            // Check if we have any bonded devices and if we're not in pairing mode
        int dev_num = esp_ble_get_bond_device_num();
        if (dev_num > 0 && !allowNewPairing) {
            // Check if the connecting device is bonded
            if (auto *bond_dev_list = static_cast<esp_ble_bond_dev_t *>(heap_caps_malloc(sizeof(esp_ble_bond_dev_t) * dev_num,
                MALLOC_CAP_INTERNAL | MALLOC_CAP_8BIT))) {
                esp_ble_get_bond_device_list(&dev_num, bond_dev_list);
                
                // Check if the connecting device's address matches any bonded device
                bool deviceBonded = false;
                for (int i = 0; i < dev_num; i++) {
                    if (memcmp(param->connect.remote_bda, bond_dev_list[i].bd_addr, ESP_BD_ADDR_LEN) == 0) {
                        deviceBonded = true;
                        break;
                    }
                }
                
                heap_caps_free(bond_dev_list);
                
                // If not bonded and not in pairing mode, disconnect
                if (!deviceBonded) {
                    Serial.println("UNAUTHORIZED CONNECTION ATTEMPT - Disconnecting!");
                    displayString("UNAUTH", 0);
                    delay(1000);
                    pServer->disconnect(param->connect.conn_id);
                    deviceConnected = false;
                    return;
                }
            }
        }

        deviceConnected = true;

        // Print the MAC address of the connecting device
        char deviceAddress[18];
        sprintf(deviceAddress, "%02X:%02X:%02X:%02X:%02X:%02X", 
                param->connect.remote_bda[0], param->connect.remote_bda[1], param->connect.remote_bda[2],
                param->connect.remote_bda[3], param->connect.remote_bda[4], param->connect.remote_bda[5]);
        Serial.print("Device MAC address: ");
        Serial.println(deviceAddress);
        
        if(esp_ble_set_encryption(param->connect.remote_bda, ESP_BLE_SEC_ENCRYPT_MITM) == ESP_OK){
            displayString("COn 6ood", 0);
        }else {
            displayString("COn FAil", 0);
        }
    };

    void onDisconnect(BLEServer* pServer) override {
        Serial.println("Device disconnected. Attempting to restart advertising...");
        displayString("COn Dis", 0);
        deviceConnected = false;
        
        int dev_num = esp_ble_get_bond_device_num();
        if (dev_num > 0) {
            displayString("Adv st", 0);
            delay(500); // Give the BLE stack time to reset
            pServer->getAdvertising()->start();
            Serial.println("Advertising restarted for reconnection of bonded devices.");
        }
    }
};

// --- 2. BLE Security Callbacks (crucial for authentication and pairing) ---
class MySecurityCallbacks : public BLESecurityCallbacks {
    // This callback is triggered when the ESP32 needs to display a passkey to the user.
    // This happens when ESP32 has ESP_IO_CAP_OUT or KBDISP and a Passkey Entry pairing is negotiated.    
    void onPassKeyNotify(uint32_t pass_key) override {
        // Security check: Only allow pairing if we're in pairing mode or if no devices are bonded yet
        int dev_num = esp_ble_get_bond_device_num();
        if (dev_num > 0 && !allowNewPairing) {
            // This is an unauthorized pairing attempt outside of pairing mode
            Serial.println("\n*************************************************");
            Serial.println("****** UNAUTHORIZED PAIRING ATTEMPT DETECTED ******");
            Serial.println("*************************************************\n");
            Serial.println("Rejecting passkey display - not in pairing mode!");
            
            // Force disconnect the device to prevent pairing
            pServer->disconnect(pServer->getConnId());
            return;
        }
        
        // If we get here, pairing is allowed
        currentDisplayedPasskey = pass_key; // Store for potential display loop
        Serial.println("\n*************************************************");
        Serial.print("****** PAIRING PASSKEY TO ENTER ON CLIENT: ");
        Serial.print(pass_key);
        Serial.println(" ******");
        Serial.println("*************************************************\n");
        Serial.println("Please enter this 6-digit passkey on your client (e.g., smartphone) to complete pairing.");
        displayString(pass_key, 2, "P5");
    }

    //NOT USED
    uint32_t onPassKeyRequest() override {
        Serial.println("Passkey Request (this callback should generally not be hit with ESP_IO_CAP_OUT)");
        return 0; // Return 0 as ESP32 is not designed to receive passkey input in this mode
    }

    //NOT USED
    bool onConfirmPIN(uint32_t pin) override {
        Serial.print("Confirm PIN (Numeric Comparison): ");
        Serial.println(pin);
        Serial.println("Does this PIN match on both devices? (Confirm on client if prompted).");
        // In a Numeric Comparison scenario, you'd ask the user to confirm match.
        // For Passkey Entry, this is not relevant.
        return true; // Assuming confirmation if hit, though ideally not.
    }    // This callback is triggered if a peer device explicitly requests security (e.g., to encrypt).
    bool onSecurityRequest() override {
        // Get number of bonded devices
        int dev_num = esp_ble_get_bond_device_num();
        
        // If we already have bonded devices, and we're not explicitly in pairing mode, reject new pairing attempts
        if (dev_num > 0 && !allowNewPairing) {
            Serial.println("SECURITY REQUEST REJECTED - Device not in pairing mode!");
            Serial.println("To pair a new device, press and hold the pairing button for 5 seconds.");
            displayString("SEC rEj", 0);
            delay(1000);
            displayClear();
            pServer->disconnect(pServer->getConnId());
            return false; // Reject the security request, preventing pairing
        }
        Serial.println("Security Request received from client. Allowing...");
        return true; // Allow the security request to initiate pairing process
    }

    // This callback is triggered once the entire authentication/pairing process is complete.
    void onAuthenticationComplete(esp_ble_auth_cmpl_t auth_cmpl) override {
        currentDisplayedPasskey = 0; // Clear the passkey once authentication is done
        lc.clearMatrix(); // Clear the display after authentication
        const String disp_val_fail = "FA1L";
        if (auth_cmpl.success) {
            Serial.println("\nAuthentication SUCCESS! Device bonded.");
            Serial.print("Bonded device address: ");
            Serial.printf("%02X:%02X:%02X:%02X:%02X:%02X\n",
                            auth_cmpl.bd_addr[0], auth_cmpl.bd_addr[1], auth_cmpl.bd_addr[2],
                            auth_cmpl.bd_addr[3], auth_cmpl.bd_addr[4], auth_cmpl.bd_addr[5]);
            Serial.println("Future connections with this device will be automatically re-encrypted.");
            displayString("SEC PASS", 0); 
        } else {
            displayString("SEC FAIL", 0);
            Serial.println("\nAuthentication FAILED! Connection terminated.");
            Serial.printf("Reason: %d\n", auth_cmpl.fail_reason);
            // It's good practice to disconnect on failed authentication to prevent unsecure connections
            pServer->disconnect(pServer->getConnId());
        }        
        
        if (pairingModeActive) {
            pServer->getAdvertising()->stop();
            pairingModeActive = false;
            allowNewPairing = false;  // Reset the pairing flag
            Serial.println("Pairing mode (advertising) deactivated after authentication attempt.");
        }
    }
};


class MyCharacteristicCallbacks: public BLECharacteristicCallbacks {
    void onWrite(BLECharacteristic *pCharacteristic) override {
        // Additional safety check - although the ESP32 BLE stack should already enforce security
        int dev_num = esp_ble_get_bond_device_num();
        if (dev_num <= 0) {
            Serial.println("WARNING: Write attempt with no bonded devices. Ignored.");
            pCharacteristic->setValue("Security error: No bonded devices");
            pCharacteristic->notify();
            return;
        }

        std::string value = pCharacteristic->getValue(); // Get the value written by the client

        if (!value.empty()) {
            Serial.print("Received command: ");
            for (int i = 0; i < value.length(); i++)
                Serial.print(value[i]);
            Serial.println();

            // --- Your Garage Door Control Logic ---
            if (value == "TRIGGER") { // Or could be a single byte like 0x01
                Serial.println("--- Triggering Garage Door Relay ---");
                digitalWrite(RELAY_PIN, HIGH); // Activate the relay
                knightRiderEffect();
                digitalWrite(RELAY_PIN, LOW); // Deactivate the relay
                Serial.println("--- Relay action complete ---");
                pCharacteristic->setValue("Command executed");
                pCharacteristic->notify();
            } else {
                Serial.println("Unknown command received.");
                pCharacteristic->setValue("Unknown command received");
                pCharacteristic->notify();
            }
        }
    }

    // You can also implement onRead() if you want the client to read something from the characteristic
    void onRead(BLECharacteristic *pCharacteristic) override {
        Serial.println("Client tried to read characteristic.");
        pCharacteristic->setValue("Status: Ready"); // Example: provide a status
    }
};
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
void loop() {

    if (!pairingModeActive && waitForButtonPressDuration(BUTTON_PIN, PAIRING_PRESS_DURATION_MILLIS, "PAIr")) {
        pServer->getAdvertising()->start();
        pairingModeActive = true;
        allowNewPairing = true; // Enable new pairing attempts during this window
        pairingModeStartTime = millis(); 
        Serial.println("\n******************************************");
        Serial.println("PAIRING MODE ACTIVATED! Advertising started.");
        Serial.println("Will remain active for 60 seconds if no connection is made.");
        Serial.println("******************************************\n");
        displayString("PAIr ACt", 0);
    }

    // --- Pairing Mode Timeout (if no connection or pairing occurs) ---
    // If pairing mode is active, no device is connected, and the timeout has passed:
    if (pairingModeActive && !deviceConnected && (millis() - pairingModeStartTime >= PAIRING_WINDOW_TIMEOUT_MILLIS)) {
        Serial.println("Pairing mode timed out. No connection made within 60 seconds.");
        pServer->getAdvertising()->stop(); // Stop advertising
        pairingModeActive = false; // Deactivate pairing mode flag
        allowNewPairing = false;   // Disable new pairing
        displayString("PAIr StP", 0);
    }

    // Check if device just connected
    if (deviceConnected && !oldDeviceConnected) {
        // Device just connected, you can add any one-time connection logic here
        oldDeviceConnected = deviceConnected;
        Serial.println("Initial connection established. Awaiting authentication...");
    }
      // Check if device just disconnected
    if (!deviceConnected && oldDeviceConnected) {
        // Device was just disconnected, advertising is handled in onDisconnect callback        oldDeviceConnected = deviceConnected;
    }
    if (lastDisplayUpdate > 0 && millis() - lastDisplayUpdate >= 5000) {
        displayClear();
    }

    delay(100); // Small delay to prevent busy-waiting
}
